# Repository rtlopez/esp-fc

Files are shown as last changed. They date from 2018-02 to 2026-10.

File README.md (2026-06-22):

# ESP-FC Flight Controller

The mini, DIY, Low cost, ESP32 based, high performance flight controller for hobbyists.

# Features

* Espressif targets (ESP32, ESP32-S3)
* ESC protocols (PWM, Oneshot125/42, Multishot, Brushed, Dshot150/300/600 bidirectional)
* PPM, SBUS, IBUS and CRSF Receivers
* Builtin ESP-NOW receiver and WiFi configuration [read more...](/docs/wireless.md)
* SPI and I2C gyro modules support (MPU6050, MPU9250, ICM20602, ICM42688, BMI160)
* Flight modes (ACRO, ANGLE, AIRMODE)
* Frames (Quad X)
* Betaflight configuration tool compatible (v10.10)
* Configurable Gyro Filters (LPF, Dynamic Notches, dTerm, RPM)
* Blackbox recording (OpenLog/OpenLager/Flash)
* Up to 4kHz gyro/loop on ESP32 with SPI gyro
* MSP and CLI protocol interface
* Resorce/Pin mapping
* In flight PID Tuning
* Buzzer, Led and voltage monitor
* Failsafe mode

# Documentation

In this repository you can find firmware code that allows you to build your own flight controller. For convenience it mimics Betaflight 4.2 compability, so that it can be configured using [betaflight-configurator](https://github.com/betaflight/betaflight-configurator). Also [online blackbox-log-viewer](https://blackbox.betaflight.com/) can be used to analyze blackbox logs. In most aspects it is similar to Betaflight, so that many configuration and tuning advices are helpfull here too. But you must be aware, that this software is not the same as Betaflight, there are some limitations and differences in functionality and performance.

> [!IMPORTANT]
> Before you begin, **read the following documentation carefully first!**.

 * [Setup Guide](/docs/setup.md)
 * [Wiring](/docs/wiring.md)
 * [CLI Commands](/docs/cli.md)
 * [WIFI and ESP-NOW Receiver](/docs/wireless.md)

Join our **[Discord Channel](https://discord.gg/jhyPPM5UEH)** to get help

# Quick Start

## Requirements

Hardware:
* ESP32 or ESP32-S3 board
* MPU9250 SPI or MPU6050 I2C gyro (GY-88, GY-91, GY-521 or similar)
* PDB with 5V BEC
* Buzzer and some electronic components (optional).

Software:
* [Betaflight Configurator](https://github.com/betaflight/betaflight-configurator/releases) (v10.10)
* [CH340 usb-serial converter driver](https://sparks.gogo.co.nz/ch340.html)

## Flashing

1. Download and unpack selected firmware from [Releases Page](https://github.com/rtlopez/esp-fc/releases)
2. Visit [ESP Tool Website](https://espressif.github.io/esptool-js/)
3. Click "Connect" and choose device port in dialog
4. Add firmware file and set Flash Address to `0x00`
5. Click "Program"
6. After success power cycle board

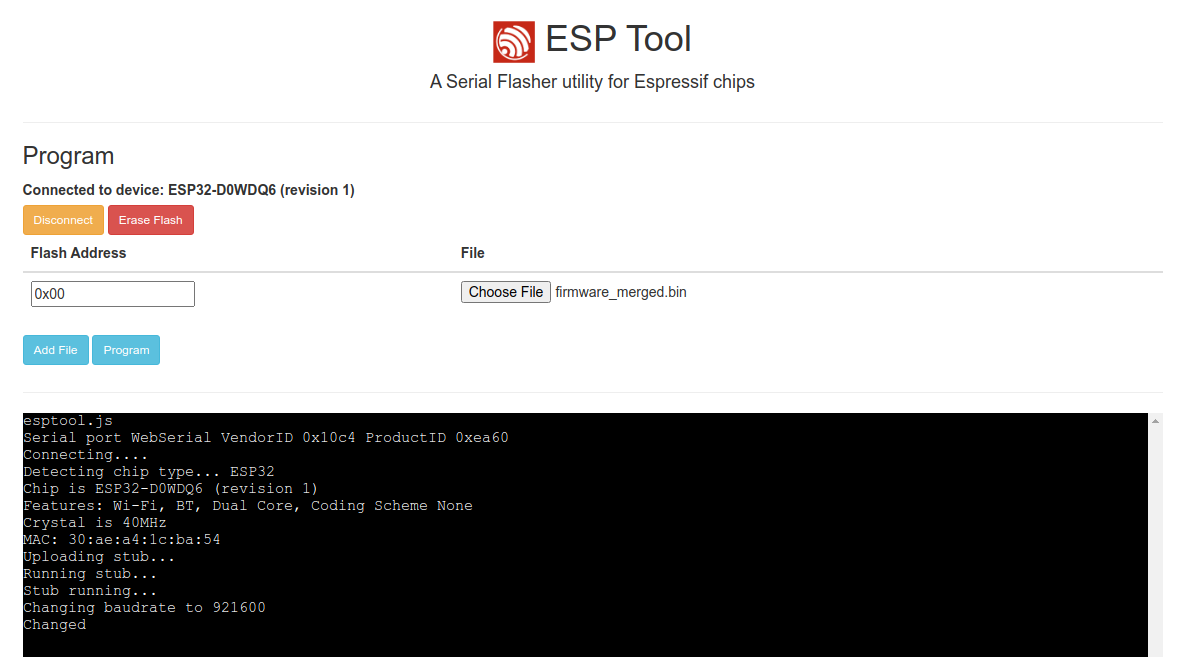
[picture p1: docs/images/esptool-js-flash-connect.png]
ESP-FC Flashing


## Setup

After flashing you need to configure few things first:

 1. Configure pinout according to your wiring, especially pin functions, you can find more information in [CLI Reference](/docs/cli.md)
 2. Connect to [Betaflight Configurator](https://github.com/betaflight/betaflight-configurator/releases) and setup to your preferences,
 3. Test motors without propellers
 4. Have fun ;)

> [!NOTE]
> Not all functions displayed in configurator are avalable in firmware. The rule of thumb is if you cannot change specific option in Betaflight Configurator, that means it is not supported. It usually rolls back to previous value after save. It is strongly recommended to follow [setup guide](/docs/setup.md).

## Wiring diagrams

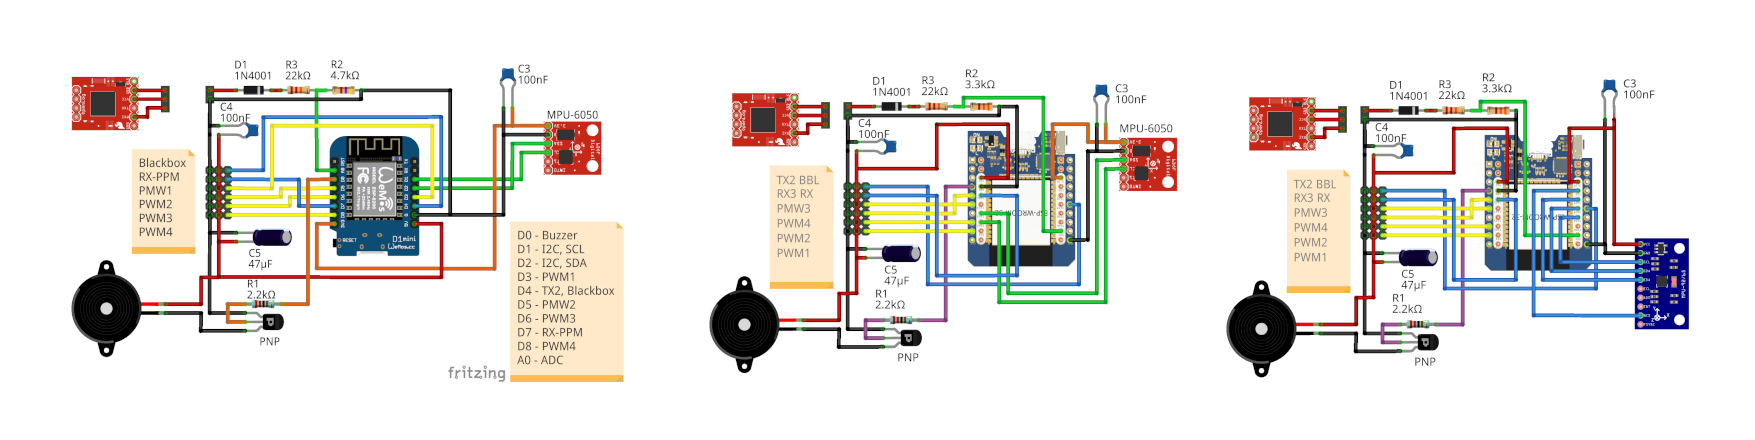
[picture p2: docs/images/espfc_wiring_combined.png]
ESP-FC example wiring diagrams


## Supported Modules

 * **ESP32** - recommended
 * **ESP32-S3** - recommended
 * **ESP32-S2** - experimantal
 * **ESP32-C3** - experimantal, lack of performance, no FPU
 * **RP2350** - experimantal, partially works
 * **RP2040** - experimantal, lack of performance, no FPU
 * **ESP8266** - obsolete, no longer developed

## Supported Sensors and Protocols

 * Gyro: MPU6050, MPU6000, MPU6500, MPU9250, ICM20602, ICM42688, BMI160
 * Barometers: BMP180, BMP280, SPL06
 * Magnetometers: HMC5883, QMC5883, AK8963, QMC5883P
 * Receivers: PPM, SBUS, IBUS, CRSF/ELRS
 * Esc Protocols: PWM, BRUSHED, ONESHOT125, ONESHOT42, MULTISHOT, DSHOT150, DSHOT300, DSHOT600
 * GPS: M8, M9, F9 & M10(dual band, all constellations configurable by cli)
 * Other protocols: MSP, CLI, BLACKBOX, ESPNOW

## Issues

You can report issues using Github [tracker](https://github.com/rtlopez/esp-fc/issues). 
You can also join our [Discord Channel](https://discord.gg/jhyPPM5UEH)

## Development

* Visual Studio Code
* [PlatformIO](https://platformio.org/install/ide?install=vscode) extension
* Git

## Todo

* Altitude Hold
* GPS Navigation
* MS5611 barometer
* Balancing robot controller

## Licence

This project is distributed under MIT Licence. Bear in mind that:

THE SOFTWARE IS PROVIDED "AS IS", WITHOUT WARRANTY OF ANY KIND, EXPRESS OR
IMPLIED, INCLUDING BUT NOT LIMITED TO THE WARRANTIES OF MERCHANTABILITY,
FITNESS FOR A PARTICULAR PURPOSE AND NONINFRINGEMENT. IN NO EVENT SHALL THE
AUTHORS OR COPYRIGHT HOLDERS BE LIABLE FOR ANY CLAIM, DAMAGES OR OTHER
LIABILITY, WHETHER IN AN ACTION OF CONTRACT, TORT OR OTHERWISE, ARISING FROM,
OUT OF OR IN CONNECTION WITH THE SOFTWARE OR THE USE OR OTHER DEALINGS IN THE
SOFTWARE.

## Donations
If you like this project and you want it to be still developed, you can support me a little.

* BTC: 1Lopez7yPtbyjfLGe892JfheDFJMMt43tW
* LTC: LV3G3sJxz9AYpDMYUp8e1LCmerFYxVY3ak

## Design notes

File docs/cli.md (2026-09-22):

# ESP-FC CLI Reference

## Help
```
help
available commands:
 help
 dump
 get param
 set param value ...
 cal [gyro]
 defaults
 save
 reboot
 scaler
 mixer
 stats
 status
 version
```

## Informational

### Version

```
version
ESPF ESP32S3 v0.0.0 0000000 Mar 13 2025 23:16:36 api=1.43 gcc=8.4.0 std=201703
```

### Status
```
status
ESPF ESP32S3 v0.0.0 0000000 Mar 13 2025 23:16:36 api=1.43 gcc=8.4.0 std=201703
STATUS:
    cpu freq: 240 MHz
  gyro clock: 3200 Hz
   gyro rate: 1600 Hz
   loop rate: 1600 Hz
  mixer rate: 1600 Hz
  accel rate: 400 Hz
   baro rate: 0 Hz
    mag rate: 0 Hz

     devices: BMI160/I2C
       input: 43 Hz, 0.00 Hz, 0.14
   arm flags: FAILSAFE RX_FAILSAFE CLI MSP
 rescue mode: 0
      uptime: 6.4
```

### Statisticss

Ensure that total CPU usage doesn't exceed 60-70%
```
stats
ESPF ESP32S3 v0.0.0 0000000 Mar 13 2025 23:16:36 api=1.43 gcc=8.4.0 std=201703
    cpu freq: 240 MHz
  gyro clock: 3200 Hz
   gyro rate: 1600 Hz
   loop rate: 1600 Hz
  mixer rate: 1600 Hz
  accel rate: 400 Hz
   baro rate: 0 Hz
    mag rate: 0 Hz

gyro_r: 187us,  117us/i,  18.7%,  1600 Hz
gyro_f:  14us,    9us/i,   1.4%,  1600 Hz
 acc_r:  45us,  114us/i,   4.5%,   399 Hz
 acc_f:   2us,    5us/i,   0.2%,   399 Hz
 imu_p:   4us,   10us/i,   0.4%,   399 Hz
 pid_o:   2us,    1us/i,   0.2%,  1600 Hz
 pid_i:   2us,    1us/i,   0.2%,  1600 Hz
 mix_p:  11us,    7us/i,   1.1%,  1600 Hz
 mix_w:  39us,   24us/i,   3.9%,  1600 Hz
 mix_r:   3us,    2us/i,   0.3%,  1600 Hz
  rx_r:   7us,    9us/i,   0.7%,   800 Hz
  rx_s:   2us,    3us/i,   0.2%,   800 Hz
  rx_a:   0us,    1us/i,   0.0%,    51 Hz
serial:   6us,    6us/i,   0.6%,   962 Hz
  wifi:   1us,    2us/i,   0.1%,   318 Hz
   bat:   7us,   65us/i,   0.7%,   102 Hz
 cpu_0: 278us,  174us/i,  27.8%,  1600 Hz
 cpu_1: 108us,   54us/i,  10.8%,  1999 Hz
  TOTAL: 386us, 23.1%
```

## Configuration

 - **defaults** - restore defaults
 - **save** - persist configuration after changes
 - **reboot** - reboot board

> [!IMPORTANT]
> if you change any parameter, remember to apply `save` and `reboot`. Without that some changes might not take effect.

## Configuration parameters

 - **dump** - dump all parameters
 - **get parameter_name** - get paramter value, list matching patameters with current values
 - **set paramter value1 [value2] [value3]** - set parameter to new value (some parameters store multiple values, ex. input)

Many parameters have similar name and meaning like Betaflight.

### Configuration examples

Get single value
```
# get gyro_lpf_type
set gyro_lpf_type PT1
```

Get multiple values
```
# get output_
set mixer_output_limit 100
set output_motor_protocol DSHOT150
set output_motor_async 0
set output_motor_rate 480
set output_servo_rate 0
set output_min_command 1000
set output_min_throttle 1050
set output_max_throttle 2000
set output_dshot_idle 450
set output_0 M N 1000 1500 2000
set output_1 M N 1000 1500 2000
set output_2 M N 1000 1500 2000
set output_3 M N 1000 1500 2000
set pin_output_0 0
set pin_output_1 14
set pin_output_2 12
set pin_output_3 15
```

Setting single value
```
set pin_output_0 0
```
> [!NOTE]
> You don't need to use `=` character for assignment

Setting milti-argument values
```
set output_0 S R
```
Note that you don't have to enter all values, you can ommit last values if they are not changed.

## Specific parameters reference

### Pin functions

Default pin assignments for ESP32-S3 is listed below
```
set pin_input_rx 6
set pin_output_0 39
set pin_output_1 40
set pin_output_2 41
set pin_output_3 42
set pin_button -1
set pin_buzzer 5
set pin_led -1
set pin_serial_0_tx 43
set pin_serial_0_rx 44
set pin_serial_1_tx 16
set pin_serial_1_rx 15
set pin_serial_2_tx 18
set pin_serial_2_rx 17
set pin_i2c_scl 10
set pin_i2c_sda 9
set pin_input_adc_vbat 1
set pin_input_adc_ibat 4
set pin_spi_0_sck 12
set pin_spi_0_mosi 11
set pin_spi_0_miso 13
set pin_spi_cs_0 8
set pin_spi_cs_1 7
set pin_spi_cs_2 -1
set pin_buzzer_invert 1
set pin_led_invert 0
```

You can swap two motor outputs (example 0 and 3) by running commands

```
set pin_output_0 42
set pin_output_3 39
save
reboot
```

### Input channel config
```
set input_0 0 1000 1500 2000 A 1500
set input_{channel} {map} {min} {neutral} {max} {fs_mode} {fs_value}
```
 - `{channel}`: raw rc channel (0-index)
 - `{map}`: map raw channel to input channel (0-index)
 - `{min/neutral/max}`: same as `rxrange` to adjust radio endpoints, scale rx input range to 1000/1500/2000, enter your min/mid/max values transmitted by radio.
 - `{fs_mode}`: fail safe mode, can be A: auto, H: hold, S: set
 - `{fs_value}`: value to use when fsMode is S(set)

### Output channel config
```
set output_0 M N 1000 1500 2000
set output_{channel} {type} {inverse} {min} {neutral} {max}
```
 - `{channel}`: output channel (0-index)
 - `{type}`: output type, can be M: motor, S: servo
 - `{inverse}`: inverse output, can be set to N: normal, R: reversed
 - `{min/neutral/max}`: limit/adjust output

### Mode conditions
```
set mode_{index} {id} {channel} {min} {max} {logic_mode} {link_id}
set mode_0 0 4 1300 2100 0 0
```
 - `{index}`: mode activator index
 - `{id}`: mode Id
 - `{channel}`: observed input channel (0-index, must be greather than 3)
 - `{min/max}`: activation range, if both are set to 900, it means inactive
 - `{logic_mode}`: NOT IMPLEMENTED, used by configurator but ignored by firmare
 - `{link_id}` - NOT IMPLEMENTED, used by configurator but ignored by firmare

Mode IDs:
 - 0: arming
 - 1: angle
 - 2: air mode
 - 3: buzzer
 - 4: failsafe

### Serial port configuration
```
set serial_0 1 115200 0
set serial_{index} {function} {msp_baud} {blackbox_baud}
```
 - `{index}`: port number (0-index)
 - `{function}`: function id
 - `{msp_baud}`: msp baud rate
 - `{blackbox_baud}`: blackbox baud rate (unused)

Serial Functions:
 - 0: none
 - 1: msp
 - 128: blackbox

### Scaler configuration

It's diferrent version of inflight adjustments, allow to control few parameters with rc channel, ex. by potentiomenters.

```
set scaler_0 769 5 20 400
set scaler_{index} {dimensions} {channel} {min_scale} {max_scale}
```

 - `{index}`: scaler instance (0-3)
 - `{dimensions}`: combination of dimentions
 - `{channel}`: observed iput channel (0-index, must be greather than 3)
 - `{min_scale/max_scale}`: min and max scale in percent

Scaler Dimensions:
 - 1: PID P component of inner loop
 - 2: PID I component of inner loop
 - 4: PID D component of inner loop
 - 8: PID F component of inner loop
 - 16: PID P component of outer loop
 - 32: PID I component of outer loop
 - 64: PID D component of outer loop
 - 128: PID F component of outer loop
 - 256: Roll Axis
 - 512: Pitch Axis
 - 1024: Yaw Axis

**Note 1**: To apply scaling you need to combine at least one PID component and Axis. You can also control multiple parameters by single channels. For example to control inner P and D on Pitch and Roll axes you need to use value 771 as dimentions (1 + 2 + 256 + 521),

**Note 2**: the scale is not uniform, in neutral position it is always 100 percent to represent original config value, if minimum is negative, then neutral position represents 0.

**Note 3**: inner loop is main loop for acro mode, outer loop refers to level mode.

### Mixer

There are few predefined mixers that can be used out-of-the box. You can choose it by setting paramter `mixer_type`

```
set mixer_type QUADX
```

Currently allowed are only:
 - QUADX (default)
 - QUAD1234 (untested)
 - TRI (untested)

You can debug mixer configuration with `mixer` command

```
# mixer
set mix_outputs 4
set mix_0 1 0 -100
set mix_1 1 1 -100
set mix_2 1 2 100
set mix_3 1 3 100
set mix_4 2 0 100
set mix_5 2 1 -100
set mix_6 2 2 100
set mix_7 2 3 -100
set mix_8 3 0 -100
set mix_9 3 1 100
set mix_10 3 2 100
set mix_11 3 3 -100
set mix_12 4 0 100
set mix_13 4 1 100
set mix_14 4 2 100
set mix_15 4 3 100
set mix_16 0 0 0
```

### Custom Mixer

To activate custom mixer you need to set mixer type to custom and declare number of outputs.

```
set mixer_type CUSTOM
set mix_outputs 4
```

Then apply your custom rules
```
set mix_0 0 0 0
set mix_{index} {src} {dst} {rate}
```
 - `{index}`: rule index
 - `{src}`: mixer source channel
 - `{dst}`: output channel (0-index)
 - `{rate}`: mix rate in percent

> [!IMPORTANT]
> You need to add a termination rule at the end, to inform mixer to stop processing. In this case set `src` argument to 0. When mixer encounters such a rule, it stops processing and ignore next rules. You can add maximum 64 rules.

Mixer Sources:
 - 0: null for termination rule
 - 1: stabilized roll
 - 2: stabilized pitch
 - 3: stabilized yaw
 - 4: thrust
 - 5: rc roll
 - 6: rc pitch
 - 7: rc yaw
 - 8: rc thrust
 - 9: rc aux 1
 - 10: rc aux 2
 - 11: rc aux 3

## All supported parameters

Use `dump` command to backup all your settings. You can then load you configuration in CLI tab. Below you can find full list of parameters.

```
set feature_gps 0
set feature_dyn_notch 0
set feature_motor_stop 0
set feature_rx_ppm 0
set feature_rx_serial 1
set feature_rx_spi 0
set feature_soft_serial 0
set feature_telemetry 0
set debug_mode NONE
set debug_axis 1
set gyro_bus AUTO
set gyro_dev AUTO
set gyro_dlpf 256Hz
set gyro_align DEFAULT
set gyro_lpf_type PT1
set gyro_lpf_freq 100
set gyro_lpf2_type PT1
set gyro_lpf2_freq 213
set gyro_lpf3_type FO
set gyro_lpf3_freq 150
set gyro_notch1_freq 0
set gyro_notch1_cutoff 0
set gyro_notch2_freq 0
set gyro_notch2_cutoff 0
set gyro_dyn_lpf_min 170
set gyro_dyn_lpf_max 425
set gyro_dyn_notch_q 300
set gyro_dyn_notch_count 4
set gyro_dyn_notch_min 80
set gyro_dyn_notch_max 400
set gyro_rpm_harmonics 3
set gyro_rpm_q 500
set gyro_rpm_min_freq 100
set gyro_rpm_fade 30
set gyro_rpm_weight_1 100
set gyro_rpm_weight_2 100
set gyro_rpm_weight_3 100
set gyro_rpm_tlm_lpf_freq 150
set gyro_offset_x -6
set gyro_offset_y -1
set gyro_offset_z 8
set accel_bus AUTO
set accel_dev AUTO
set accel_lpf_type BIQUAD
set accel_lpf_freq 15
set accel_offset_x 0
set accel_offset_y 0
set accel_offset_z 0
set mag_bus AUTO
set mag_dev NONE
set mag_align DEFAULT
set mag_filter_type BIQUAD
set mag_filter_lpf 10
set mag_offset_x 0
set mag_offset_y 0
set mag_offset_z 0
set mag_scale_x 1000
set mag_scale_y 1000
set mag_scale_z 1000
set baro_bus AUTO
set baro_dev NONE
set baro_lpf_type BIQUAD
set baro_lpf_freq 3
set gps_min_sats 8
set gps_set_home_once 1
set board_align_roll 0
set board_align_pitch 0
set board_align_yaw 0
set vbat_source NONE
set vbat_scale 100
set vbat_mul 1
set vbat_div 10
set vbat_cell_warn 350
set ibat_source NONE
set ibat_scale 100
set ibat_offset 0
set fusion_mode MAHONY
set fusion_gain_p 50
set fusion_gain_i 5
set input_rate_type ACTUAL
set input_roll_rate 20
set input_roll_srate 40
set input_roll_expo 0
set input_roll_limit 1998
set input_pitch_rate 20
set input_pitch_srate 40
set input_pitch_expo 0
set input_pitch_limit 1998
set input_yaw_rate 30
set input_yaw_srate 36
set input_yaw_expo 0
set input_yaw_limit 1998
set input_deadband 3
set input_min 885
set input_mid 1500
set input_max 2115
set input_filter_type FILTER
set input_lpf_type PT3
set input_lpf_freq 0
set input_lpf_factor 50
set input_ff_lpf_type PT3
set input_ff_lpf_freq 0
set input_rssi_channel 0
set input_0 0 1000 1500 2000 A 1500
set input_1 1 1000 1500 2000 A 1500
set input_2 3 1000 1500 2000 A 1500
set input_3 2 1000 1500 2000 A 1000
set input_4 4 1000 1500 2000 H 1500
set input_5 5 1000 1500 2000 H 1500
set input_6 6 1000 1500 2000 H 1500
set input_7 7 1000 1500 2000 H 1500
set input_8 8 1000 1500 2000 H 1500
set input_9 9 1000 1500 2000 H 1500
set input_10 10 1000 1500 2000 H 1500
set input_11 11 1000 1500 2000 H 1500
set input_12 12 1000 1500 2000 H 1500
set input_13 13 1000 1500 2000 H 1500
set input_14 14 1000 1500 2000 H 1500
set input_15 15 1000 1500 2000 H 1500
set failsafe_delay 4
set failsafe_kill_switch 0
set vtx_power 0
set vtx_channel 8
set vtx_band 1
set vtx_low_power_disarm 0
set serial_0 1 115200 0
set serial_1 1 115200 0
set serial_2 64 115200 0
set serial_soft_0 1 115200 0
set serial_usb 1 115200 0
set scaler_0 0 0 20 400
set scaler_1 0 0 20 400
set scaler_2 0 0 20 400
set mode_0 0 4 900 900 0 0
set mode_1 0 4 900 900 0 0
set mode_2 0 4 900 900 0 0
set mode_3 0 4 900 900 0 0
set mode_4 0 4 900 900 0 0
set mode_5 0 4 900 900 0 0
set mode_6 0 4 900 900 0 0
set mode_7 0 4 900 900 0 0
set pid_sync 1
set pid_roll_p 42
set pid_roll_i 85
set pid_roll_d 24
set pid_roll_f 72
set pid_pitch_p 46
set pid_pitch_i 90
set pid_pitch_d 26
set pid_pitch_f 76
set pid_yaw_p 45
set pid_yaw_i 90
set pid_yaw_d 0
set pid_yaw_f 72
set pid_level_p 45
set pid_level_i 0
set pid_level_d 0
set pid_level_angle_limit 55
set pid_level_rate_limit 300
set pid_level_lpf_type PT1
set pid_level_lpf_freq 90
set pid_yaw_lpf_type PT1
set pid_yaw_lpf_freq 90
set pid_dterm_lpf_type PT1
set pid_dterm_lpf_freq 128
set pid_dterm_lpf2_type PT1
set pid_dterm_lpf2_freq 128
set pid_dterm_notch_freq 0
set pid_dterm_notch_cutoff 0
set pid_dterm_dyn_lpf_min 60
set pid_dterm_dyn_lpf_max 145
set pid_dterm_weight 30
set pid_iterm_limit 30
set pid_iterm_zero 1
set pid_iterm_relax RP
set pid_iterm_relax_cutoff 15
set pid_tpa_scale 10
set pid_tpa_breakpoint 1650
set mixer_sync 1
set mixer_type QUADX
set mixer_yaw_reverse 0
set mixer_throttle_limit_type NONE
set mixer_throttle_limit_percent 100
set mixer_output_limit 100
set output_motor_protocol DSHOT300
set output_motor_async 0
set output_motor_rate 480
set output_motor_poles 14
set output_servo_rate 0
set output_min_command 1000
set output_min_throttle 1070
set output_max_throttle 2000
set output_dshot_idle 550
set output_dshot_telemetry 0
set output_0 M N 1000 1500 2000
set output_1 M N 1000 1500 2000
set output_2 M N 1000 1500 2000
set output_3 M N 1000 1500 2000
set pin_input_rx 6
set pin_output_0 39
set pin_output_1 40
set pin_output_2 41
set pin_output_3 42
set pin_button -1
set pin_buzzer 5
set pin_led -1
set pin_serial_0_tx 43
set pin_serial_0_rx 44
set pin_serial_1_tx 16
set pin_serial_1_rx 15
set pin_serial_2_tx 18
set pin_serial_2_rx 17
set pin_i2c_scl 13
set pin_i2c_sda 12
set pin_input_adc_vbat 1
set pin_input_adc_ibat 4
set pin_spi_0_sck -1
set pin_spi_0_mosi -1
set pin_spi_0_miso -1
set pin_spi_cs_0 8
set pin_spi_cs_1 7
set pin_spi_cs_2 -1
set pin_buzzer_invert 1
set pin_led_invert 0
set i2c_speed 800
set rescue_config_delay 30
set telemetry_interval 1000
set blackbox_dev NONE
set blackbox_mode NORMAL
set blackbox_rate 32
set blackbox_log_acc 1
set blackbox_log_alt 1
set blackbox_log_bat 1
set blackbox_log_debug 1
set blackbox_log_gps 1
set blackbox_log_gyro 1
set blackbox_log_gyro_raw 1
set blackbox_log_mag 1
set blackbox_log_motor 1
set blackbox_log_pid 1
set blackbox_log_rc 1
set blackbox_log_rpm 1
set blackbox_log_rssi 1
set blackbox_log_sp 1
set model_name
set wifi_ssid
set wifi_pass
set wifi_tcp_port 1111
set mix_outputs 0
set mix_0 0 0 0
set mix_1 0 0 0
set mix_2 0 0 0
set mix_3 0 0 0
set mix_4 0 0 0
set mix_5 0 0 0
set mix_6 0 0 0
set mix_7 0 0 0
set mix_8 0 0 0
set mix_9 0 0 0
set mix_10 0 0 0
set mix_11 0 0 0
set mix_12 0 0 0
set mix_13 0 0 0
set mix_14 0 0 0
set mix_15 0 0 0
set mix_16 0 0 0
set mix_17 0 0 0
set mix_18 0 0 0
set mix_19 0 0 0
set mix_20 0 0 0
set mix_21 0 0 0
set mix_22 0 0 0
set mix_23 0 0 0
set mix_24 0 0 0
set mix_25 0 0 0
set mix_26 0 0 0
set mix_27 0 0 0
set mix_28 0 0 0
set mix_29 0 0 0
set mix_30 0 0 0
set mix_31 0 0 0
set mix_32 0 0 0
set mix_33 0 0 0
set mix_34 0 0 0
set mix_35 0 0 0
set mix_36 0 0 0
set mix_37 0 0 0
set mix_38 0 0 0
set mix_39 0 0 0
set mix_40 0 0 0
set mix_41 0 0 0
set mix_42 0 0 0
set mix_43 0 0 0
set mix_44 0 0 0
set mix_45 0 0 0
set mix_46 0 0 0
set mix_47 0 0 0
set mix_48 0 0 0
set mix_49 0 0 0
set mix_50 0 0 0
set mix_51 0 0 0
set mix_52 0 0 0
set mix_53 0 0 0
set mix_54 0 0 0
set mix_55 0 0 0
set mix_56 0 0 0
set mix_57 0 0 0
set mix_58 0 0 0
set mix_59 0 0 0
set mix_60 0 0 0
set mix_61 0 0 0
set mix_62 0 0 0
set mix_63 0 0 0
```

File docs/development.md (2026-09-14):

# Development

## Building and flashing

```
pio run                      # build all targets
pio run -e <target>          # build specific target like: esp32,esp32s3,...
pio run -e esp32 -t upload   # build and flash device
pio test -e native           # run unit tests
pio check                    # run static anlysis
pio run -t check_format      # check code style
pio run -e native -t format  # format code
```

## Docker

If you don't want to install PlatformIO, you can use Docker Environment

general usage
```
docker compose run --rm espfc <pio command>
```

examples

```
docker compose run --rm espfc pio run -e esp32
docker compose run --rm espfc pio test -e native
```

> [!NOTE]
> Keep in mind, that to be able to flash device, additional effort is required as by default docker is isolated enviroment devices are't accessible.

## VSCode

This project is based on [platformio](https://platformio.org/), it is recommended to install it as VSCode IDE extension.

1. if you don't have VSCode yet? visit https://code.visualstudio.com/download
2. then install https://platformio.org/install/ide?install=vscode

## Contribution

If you want to include your changes in this project, you need to make PR (Pull Request) on github.

### How to contribute to Esp-fc project

1. Fork the repository

Click the Fork button on the project’s GitHub page to create your own copy.

2. Clone your fork

```
git clone https://github.com/your-username/project-name.git
```

3. Create a new branch

```
git checkout -b feature/my-change
```

4. Make your changes

- Edit files, add features, or fix bugs.
- Run tests and static anlysis tools.
- Collect eveidence that proves your changes do the job

5. Commit your changes

```
git add .
git commit -m "Add short description of changes"
```

6. Push the branch to your fork

```
git push origin feature/my-change
```

7. Open a Pull Request (PR)

Go to your fork on GitHub and click Compare & pull request. Add a clear title and description, then submit the PR. Wait for review. Project maintainers may request changes before merging your contribution.

### What requirements must be met for a PR to be accepted?

1. Provide clear change description with reasoning what type of problem you are trying to resolve
2. Provide evidence that feature you deliver works as expected and do not breaks any existing functionality
3. In PR address only one problem or feature
4. Ensure that unittests are passing and static alanysis tools do not report any errors
5. Avoid commiting unnecesary changes
6. Untested changes will not be accepted

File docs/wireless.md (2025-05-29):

# ESP-FC Wireless functions

Espressif modules have a built-in WiFi module that can be used for configuration and control.

## WiFi configuration

> [!NOTE]
> To be able to configure device using WiFi connection, you need to enable `SOFTSERIAL` function. WiFi function can only be used to configure device. Whilst WiFi is active, it is not possible to ARM controller and reboot is required.

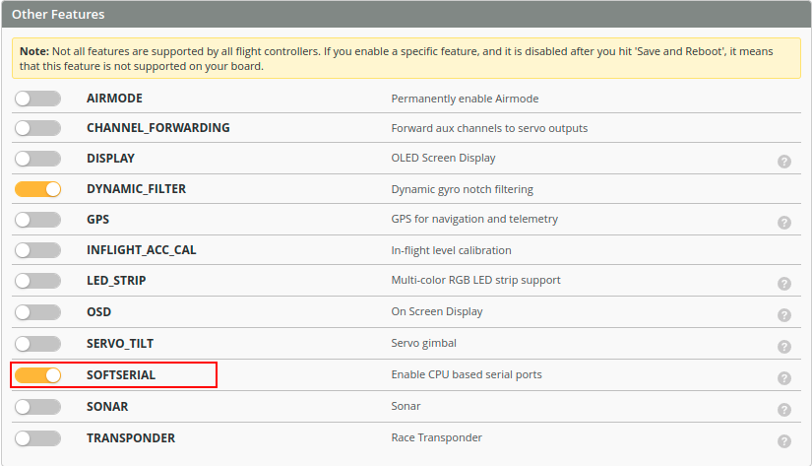
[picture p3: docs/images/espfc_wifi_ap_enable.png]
Enable WiFi


WiFi will start its own Access-Point if board will not detect receiver signal for at least 30 seconds (stay in failsafe mode since boot). Name of this AP is `ESP-FC` and it is open network. If you connect to this AP, then choose `Manual Selection` and type `tcp://192.168.4.1:1111` 

Connect to ESP-FC AP

You can also automatically connect ESP-FC to your home network. To achive that, go to the CLI tab, and enter your network name and secret.
```
set wifi_ssid MY-HOME-NET
set wifi_pass MY-HOME-PASS
```
> [!NOTE]
> Network name and pass must not contains spaces.

then you can check status of connection by typing `wifi` in CLI tab.
```
wifi 
ST IP4: tcp://0.0.0.0:1111
ST MAC: 30:30:F9:6E:10:74
AP IP4: tcp://192.168.4.1:1111
AP MAC: 32:30:F9:6E:10:74
```
In this mode you need to discover IP address granted by DHCP. In line `ST IP4` is the address that you need to use in configurator. If there is `0.0.0.0`, that means that FC was not able to connect to home network.

## ESP-NOW control

ESP-NOW is a proprietary wireless communication protocol defined by Espressif, which enables the direct, quick and low-power control of smart devices, without the need of a router. 

As there are no real transmitters usng this protocol on the market, you have to build your own transmitting module first. If you alredy own RC transmitter with JR bay, you can use another ESP32 module. In this case follow [espnow-rclink-tx](https://github.com/rtlopez/espnow-rclink-tx) instructions.

In ESP-FC you have to choose `SPI Rx (e.g. built-in Rx)` as Receiver mode in Receiver tab.

ESP-FC ESP-NOW Reciever

Transmitter and receiver binds automatically after power up, you don't need to do anything. Recomended startup procedure is:
1. turn on transmitter first
2. next power up receiver/flight controller

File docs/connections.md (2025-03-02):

# WEMOS D1 MINI pinout
```
Pin | Function         | ESP-8266 Pin | ESPFC external device
----+------------------+--------------+----------------------------------------------
TX  | TXD0             | TXD, GPIO1   | (UART0 TX) | CLI | MSP | OSD
RX  | RXD0             | RXD, GPIO3   | (UART0 RX) | CLI | MSP | OSD
A0  | Analog In,  3.3V | A0           | Batery voltage or current sensor, analog only
D0  | IO               | GPIO16       | LED | BUZZER (output recommended, no interrupts)
D1  | IO, SCL          | GPIO5        | I2C Gyro, Compas, Pressure and other sensors
D2  | IO, SDA          | GPIO4        | I2C Gyro, Compas, Pressure and other sensors
D3  | IO, PU           | GPIO0        | PWM 1 (servo/motor)
D4  | IO, PU, LD, TXD1 | GPIO2        | Blackbox (UART1 TX)
D5  | IO, SCK          | GPIO14       | PWM 2 (servo/motor)
D6  | IO, MISO         | GPIO12       | PWM 3 (servo/motor)
D7  | IO, MOSI         | GPIO13       | PPM RX | PWM
D8  | IO, SS, PD       | GPIO15       | PWM 4 (servo/motor)
G   | Ground           | GND          | Ground
5V  | 5V               | N/A          | 5V power
3V3 | 3.3V             | 3.3V         | 3.3V power - to I2C devices
RST | Reset            | RST          | Reset switch (optional)
```

## Legend:
```
   PU - 10k pull up
   PD - 10k pull down
 RXD0 - UART0 hardware RX
 TXD0 - UART0 hardware TX
 TXD1 - UART1 hardware TX
   LD - builtin LED
```

## Notice:
```
 A0 - In ESP-8266 is 1.0V range, Wemos has 220k:100k divider for 3.3V range, 22k:4k7 additional divider required for 4S Lipo
 D0 - No iterrupts (recommended output)
 D3, GPIO0 - if low at boot, then board enters to flashing mode (avoid using as input)
 D4, GPIO2 - must be high during flashing (avoid using as input)
 D8, GPIO15 - must be low during flashing or boot (avoid using as input)
```
https://github.com/esp8266/esp8266-wiki/wiki/Boot-Process#esp-boot-modes

## Wemos D1 mini board layout:
```
      /-----------\
   TX |           | RST
   RX |           | A0
   D1 |           | D0
   D2 |           | D5 ~>
<~ D3 |           | D6 ~>
<~ D4 |           | D7 ~<
  GND |           | D8 ~>
   5v |           | 3.3V
      +---|---|---+
           USB
```

# ESP32 pinout
```
Pin | Name | Function                                   | ESPFC external device
----+------+--------------------------------------------+----------------------------------------------
 0  |      | PU,ADC2_CH1,CLK_OUT1                       | >  BUTTON
 1  | TXD  | U0TXD,CLK_OUT3                             |    TX0, PROG, MSP
 2  |      | ADC2_CH2,HSPIWP,HS2_DATA0,SD_DATA0         | >  LED
 3  | RXD  | U0RXD,CLK_OUT2                             |    RX0, PROG, MSP
 4  |      | ADC2_CH0,HSPIHD,HS2_DATA1,SD_DATA1         |    M2
 5  |      | VSPICS0,HS1_DATA6                          | >  SPI_CS0_GYRO, SPI0_SS
12  | TD1  | PD,ADC2_CH5,MTDI,HSPIQ,HS2_DATA2,SD_DATA2  | >  M3, SPI1_MISO
13  | TCK  | ADC2_CH4,MTCK,HSPID,HS2_DATA3,SD_DATA3     |    SPI_CS1_BARO, SPI1_MOSI
14  | TMS  | ADC2_CH6,MTMS,HSPICLK,HS2_CLK,SD_CLK       | $  FREE, SPI1_SCK
15  | TD0  | PU,ADC2_CH3,MTDO,HSPICS0,HS2_CMD,SD_CMD    | >  FREE, SPI_CS2_SDCARD, SPI1_SS
16  |      | HS1_DATA4,U2RXD                            |    RX2
17  |      | HS1_DATA5,U2TXD                            |    TX2
18  |      | VSPICLK,HS1_DATA7                          |    SPI0_SCK
19  |      | VSPIQ,U0CTS                                |    SPI0_MISO
21  |      | VSPIHD                                     |    I2C0_SDA
22  |      | VSPIWP,U0RTS                               |    I2C0_SCL
23  |      | VSPID,HS1_STROBE                           |    SPI0_MOSI
25  |      | ADC2_CH8,DAC1                              |    M1
26  |      | ADC2_CH9,DAC2                              |    BUZZER
27  |      | ADC2_CH7                                   |    M0
32  |      | ADC1_CH4,XTAL                              |    RX1
33  |      | ADC1_CH5,XTAL                              |    TX1
34  |      | ADC1_CH6                                   | <$ ADC, INTR
35  |      | ADC1_CH7                                   | <  PPM, ADC, INTR
36  | SVP  | ADC1_CH0                                   | <  ADC_VOLTAGE
37  | -    | ADC1_CH1                                   | -  N/A
38  | -    | ADC1_CH2                                   | -  N/A
39  | SVN  | ADC1_CH3                                   | <  ADC_CURRENT
```

## Legend
```
 '>' recommended output only
 '<' input only
 '$' free
 '-' not available
```
GPIO `0, 2, 5, 12, 15` recommended as output because of boot process impact
GPIO `34-39` are input-only by chip
GPIO `6-11` are reserved for integrated flash
GPIO `20,24,28,29,30,31` does not exist

- GPIO0 - Low/GND	ROM serial bootloader for esptool.py, High/VCC	Normal execution mode
- GPIO2 - GPIO2 must also be either left unconnected/floating, or driven Low, in order to enter the serial bootloader. In normal boot mode (GPIO0 high), GPIO2 is ignored.
- GPIO12 - If driven High, flash voltage (VDD_SDIO) is 1.8V not default 3.3V. Has internal pull-down, so unconnected = Low = 3.3V. May prevent flashing and/or booting if 3.3V flash is used and this pin is pulled high, causing the flash to brownout. See the ESP32 datasheet for more details.
- GPIO15 - If driven Low, silences boot messages printed by the ROM bootloader. Has an internal pull-up, so unconnected = High = normal output.
- GPIO5 - configures SDIO Slave in "Download Boot"

https://github.com/espressif/esptool/wiki/ESP32-Boot-Mode-Selection

## ESP32 mini board layout
```
                  /-------------\
 GND      RST     |             |  TXD (1)    GND
  NC      SVP(36) |             |  RXD (3)    IO(27)
 SVN(39)   IO(26) |             |   IO(22)    IO(25)
  IO(35)   IO(18) |             |   IO(21)    IO(32)
  IO(33)   IO(19) |             |   IO(17)   TD1(12)
  IO(34)   IO(23) |             |   IO(16)    IO(04)
 TMS(14)   IO(05) |             |  GND        IO(00)
  NC      3V3     |             |  VCC(5v)    IO(02)
 SD2(09)  TCK(13) |             |  TD0(15)   SD1(08)
 CMD(11)  SD3(10) |             |  SD0(07)   CLK(06)
                  +----|---|----+
                        USB
```

# ESP32-S3

https://docs.espressif.com/projects/esp-idf/en/latest/esp32s3/api-reference/peripherals/gpio.html

```
Pin | Function             | ESPFC external device
----+------+---------------+----------------------------------------------
 0  | Strapping            |
 1  | ADC1_CH0             | ADC_VOLTAGE
 2  | ADC1_CH1             | DEBUG
 3  | ADC1_CH2, Strapping  |
 4  | ADC1_CH3             | ADC_CURRENT
 5  | ADC1_CH4             | BUZZER
 6  | ADC1_CH5             | PPM
 7  | ADC1_CH6             | SPI_CS_BARO
 8  | ADC1_CH7             | SPI_CS_GYRO
 9  | ADC1_CH8             | I2C_0_SDA
10  | ADC1_CH9             | I2C_0_SCK
11  | ADC2_CH0             | SPI_0_MOSI
12  | ADC2_CH1             | SPI_0_SCK
13  | ADC2_CH2             | SPI_0_MISO
14  | ADC2_CH3             | ?
15  | ADC2_CH4             | RX1
16  | ADC2_CH5             | TX1
17  | ADC2_CH6             | RX2
18  | ADC2_CH7             | TX2
19  | ADC2_CH8, USB        | USB
20  | ADC2_CH9, USB        | USB
21  | RTC_21               | ?
38  | RGB                  | LED_RGB
39  |                      | M0
40  |                      | M1
41  |                      | M2
42  |                      | M3
43  | U1TX                 | TX0
44  | U1RX                 | RX0
45  |                      | ?
46  | Strapping            | SPI_CS_SD
47  | Strapping            | ?
48  |                      | ?

RESERVED
26  | FLASH                |
27  | FLASH                |
28  | FLASH                |
29  | FLASH                |
30  | FLASH                |
31  | FLASH                |
32  | FLASH                |
33  | FLASH                |
34  | FLASH                |
35  | FLASH                |
36  | FLASH                |
37  | FLASH                |

UNAVAILABLE
22, 23, 24, 25
```

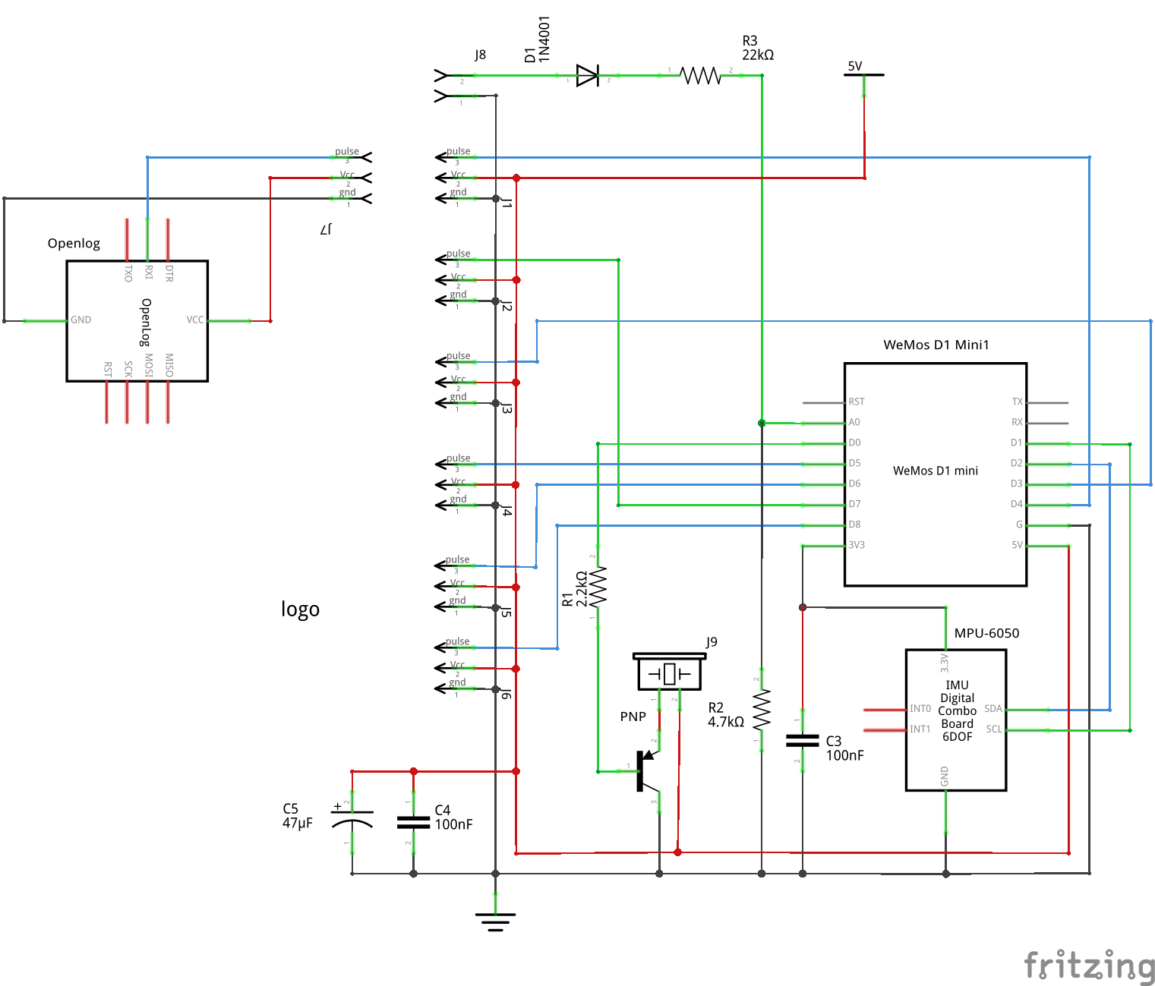
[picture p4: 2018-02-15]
docs/images/espfc_wemos_d1_mini_schematic.png

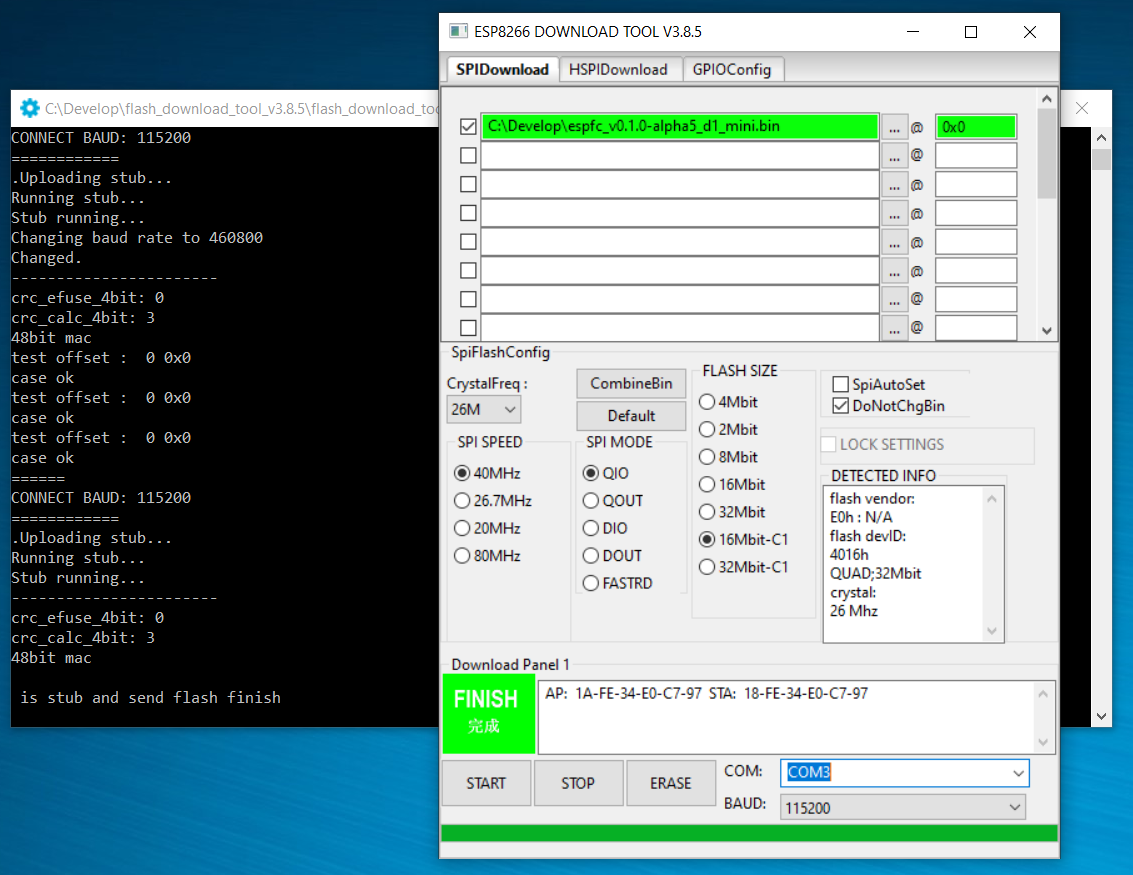
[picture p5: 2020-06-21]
docs/images/espfc_flashing.png

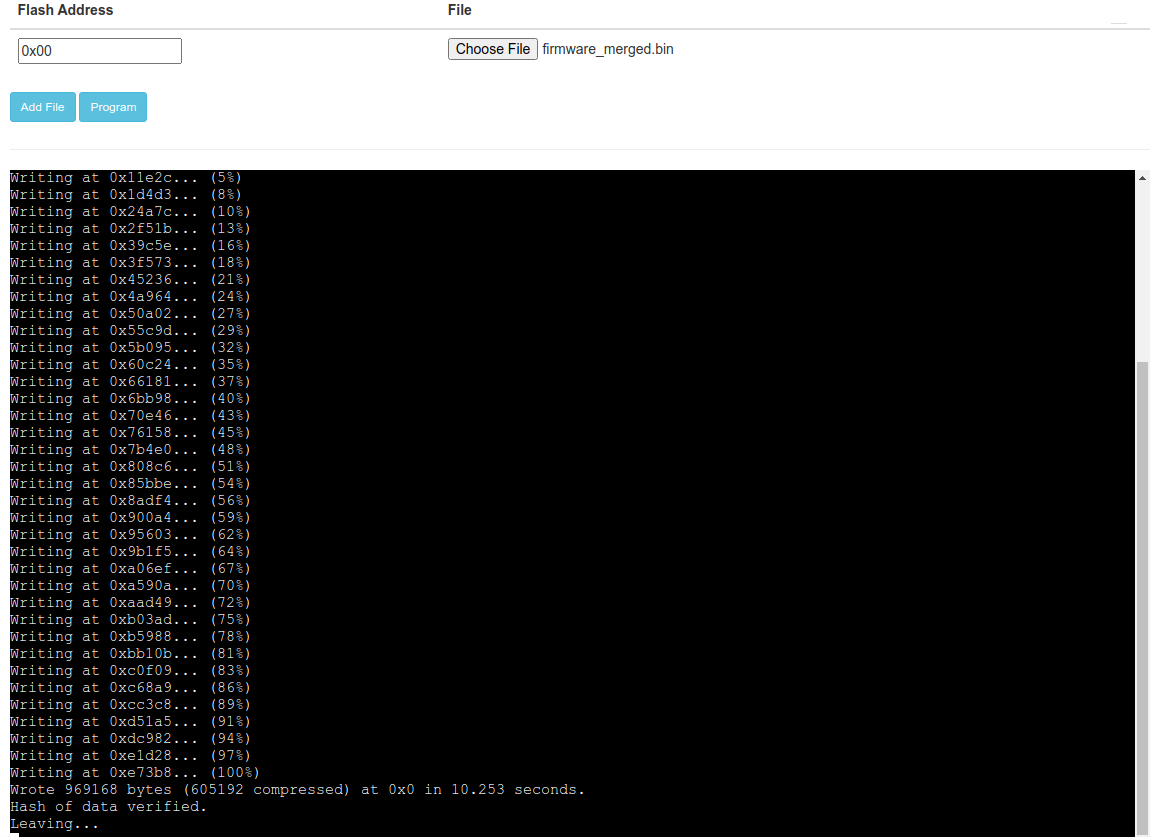
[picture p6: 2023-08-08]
docs/images/esptool-js-flash-flashed.png

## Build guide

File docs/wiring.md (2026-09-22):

# ESP-FC wiring examples and PIN mapping

ESP32 MCUs allows to remap pins, so the wiring is not final and you can remap intputs and outputs to your needs. To change pin function go to the CLI and use `get pin` command to check current assignment. For example, to set first output to pin 1 use command

`set pin_output_0 1`

Tu unmap pin function use -1 as pin number

`set pin_output_3 -1`

> [!NOTE]
> There are still some limitations in remapping. Not all pins can be used with all functions. Some pins are input only, others are strapping pins and may prevent from booting if used incorrectly. please consult MCU documentation for available options. Default layout is proven to work.

## Default I2C pin mapping for gyro modules

| Module Pin | CLI Name | ESP32 | ESP32-S3 |
|---|---|---:|---:|
| SCK/SCL | `pin_i2c_scl` | 22 | 10 |
| SDA/SDI | `pin_i2c_sda` | 21 | 9 |

> [!NOTE]
> I2C driver accepts only pins from 1 to 31

## Default SPI pin mapping gyro modules

| Module Pin  | CLI Name | ESP32 | ESP32-S3 |
|---|---|---:|---:|
| SCK/SCL | `pin_spi_0_sck`  | 18 | 12 |
| SDA/SDI | `pin_spi_0_mosi` | 23 | 11 |
| SAO/SDO/ADO | `pin_spi_0_miso` | 19 | 13 |
| NCS | `pin_spi_cs_0` |  5 |  8 |
| CSB* | `pin_spi_cs_1` | 13 |  7 |

**Note:** `CSB` is required for barometer on 10-DOF MPU-9250 modules

> [!TIP]
> For better performance preffer SPI

## Default Servo/Motor output mapping

| Motor  | CLI name | ESP32 | ESP32-S3 |
|---:|---|---:|---:|
| 1 | `pin_output_0` | 27 | 39 |
| 2 | `pin_output_1` | 25 | 40 |
| 3 | `pin_output_2` | 4 | 41 |
| 4 | `pin_output_3` | 12 | 42 |

## Default Uart/Serial pin mapping

| Uart | CLI name | ESP32 | ESP32-S3 |
|-----:|---|---:|---:|
| RX 1 | `pin_serial_0_rx` |  3 | 44 |
| TX 1 | `pin_serial_0_tx` |  1 | 43 |
| RX 2 | `pin_serial_1_rx` | 32 | 15 |
| TX 2 | `pin_serial_1_tx` | 33 | 16 |
| RX 3 | `pin_serial_2_rx` | 16 | 17 |
| TX 3 | `pin_serial_2_tx` | 17 | 18 |

## Default Analog pin mapping

| Uart | CLI name | ESP32 | ESP32-S3 |
|---:|---|---:|---:|
| Voltage | `pin_input_adc_vbat` |  36 | 1 |
| Current | `pin_input_adc_ibat` |  39 | 4 |

> [!NOTE]
> On ESP32 choose only pins assigned to ADC1 channels

## Default PPM receiver pin mapping

| Uart | CLI name | ESP32 | ESP32-S3 |
|---:|---|---:|---:|
| PPM | `pin_input_rx` |  35 | 6 |

## Other pin functions

| CLI name | ESP32 | ESP32-S3 | Comment |
|---|---:|---:|---|
| `pin_buzzer` |  0 | 5 | Status buzzer |
| `pin_led` |  26 | - | Status led |

## Example ESP32 SPI MPU-6500/MPU-9250 gyro

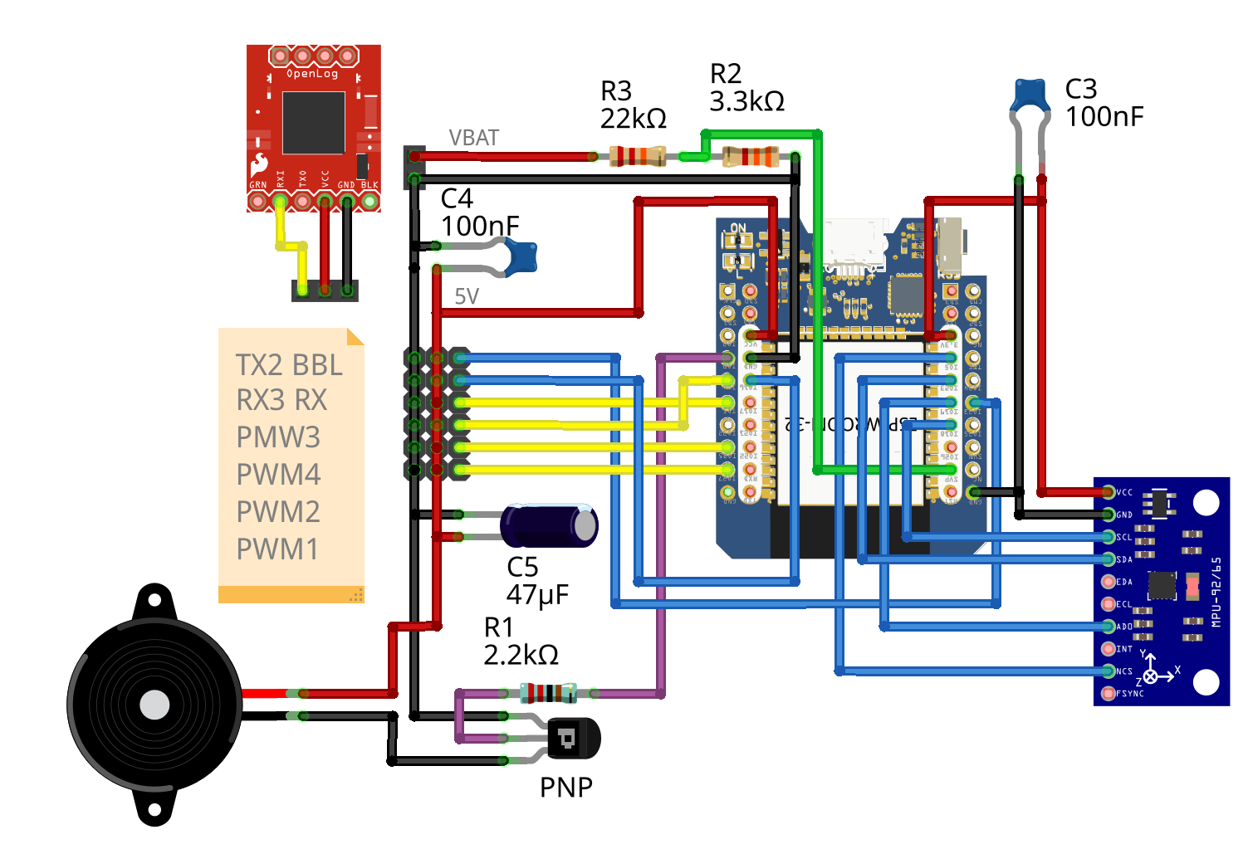
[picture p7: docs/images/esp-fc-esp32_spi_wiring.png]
ESP-FC ESP32 SPI Wiring


## Example ESP32 I2C MPU-6050 gyro

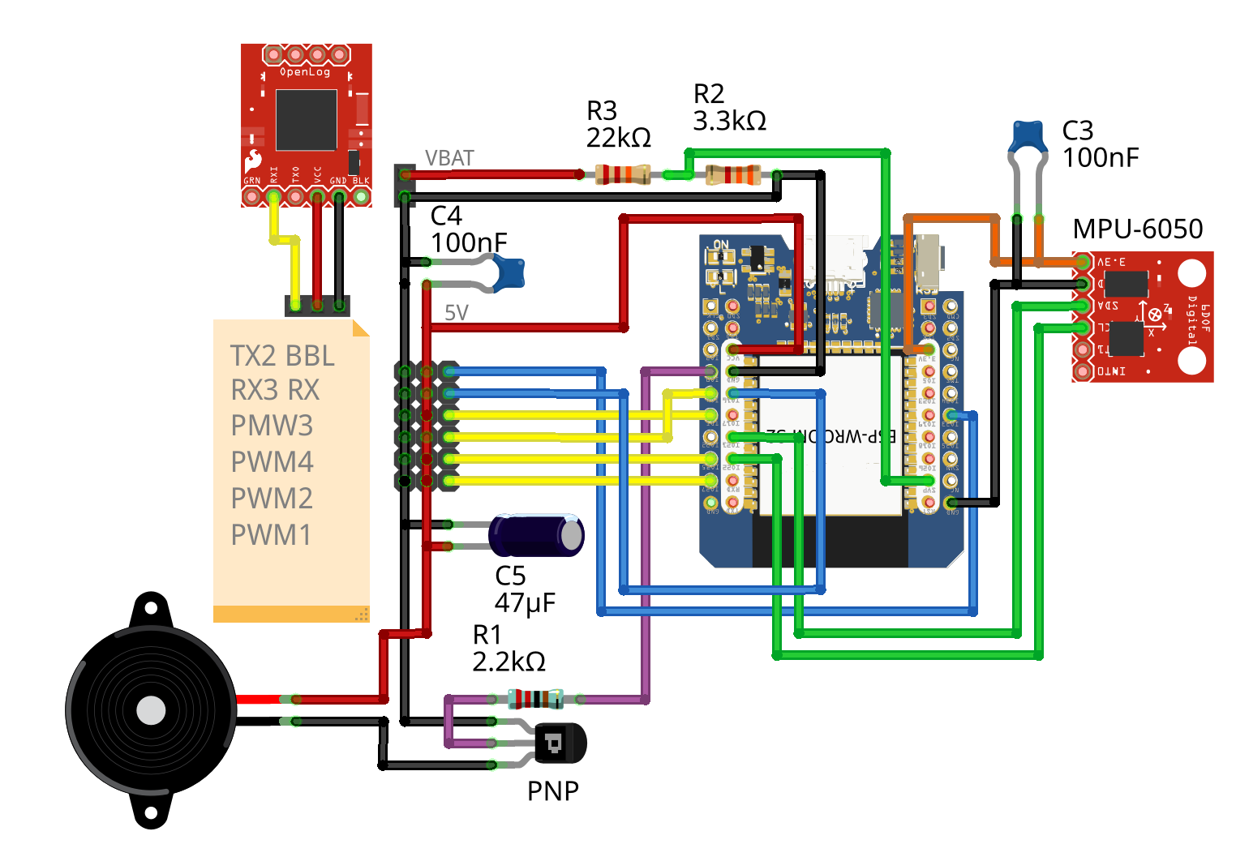
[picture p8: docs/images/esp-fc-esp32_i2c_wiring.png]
ESP-FC ESP32 I2C Wiring


## Example ESP8266 I2C MPU-6050 gyro

ESP8266 has limited ability to remap pins, use `get pin` command to list available options.

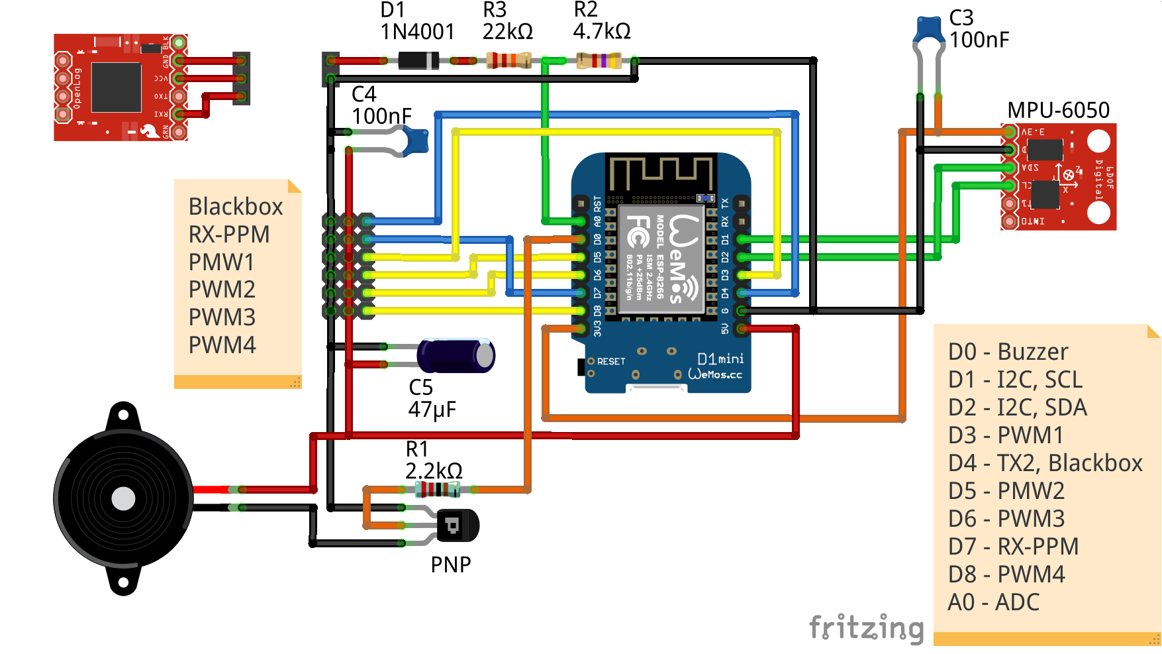
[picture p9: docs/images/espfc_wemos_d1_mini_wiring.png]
ESP-FC ESP8266 I2C Wiring


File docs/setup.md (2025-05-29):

# Setup

This page describe steps absolutly required to proceed before first flight.

## Connecting to Betaflight Configurator

Once you download and install [Betaflight configurator](https://github.com/betaflight/betaflight-configurator) you need to change few options first. Open configurator and go to **Options** tab, and then
1. Disable `Advanced CLI AutoComplete`
2. Enable `Show all serial devices`
3. Disable `Auto-Connect`

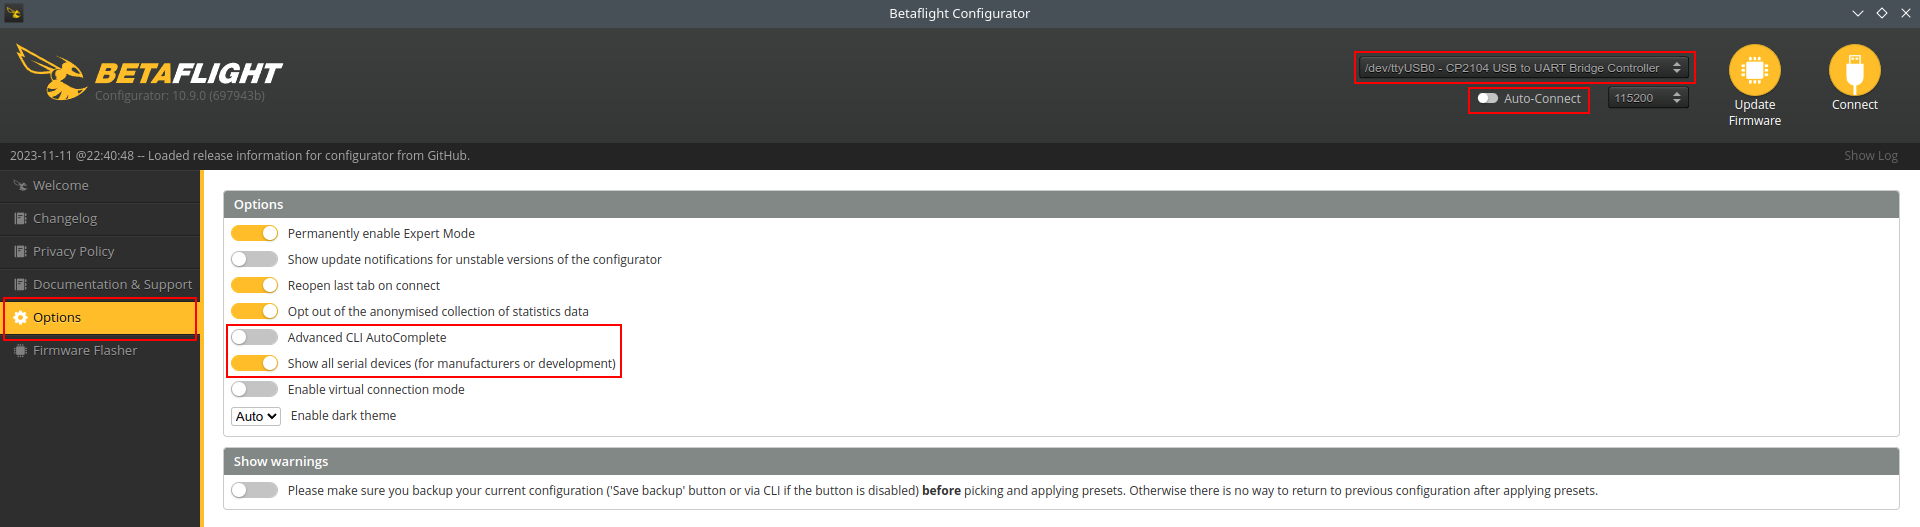
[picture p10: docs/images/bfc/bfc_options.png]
Options


Then select your device from list and click connect.

> [!NOTE]
> Not all functions displayed in configurator are avalable in firmware. The rule of thumb is if you cannot change specific option in Betaflight Configurator, that means it is not supported. It usually rolls back to previous value after save.

> [!NOTE]
> Leaving some tabs, especially CLI requires you to click "Disconnect" button twice, and then click "Connect" again.

## Configure wiring

Go to the `CLI` tab and type `get pin`. This command will show what pins are associated to specified functions. If you wiring is diferrent, you can make some adjustments here. For more details, see [Pin Functions CLI Reference](/docs/cli.md#pin-functions)

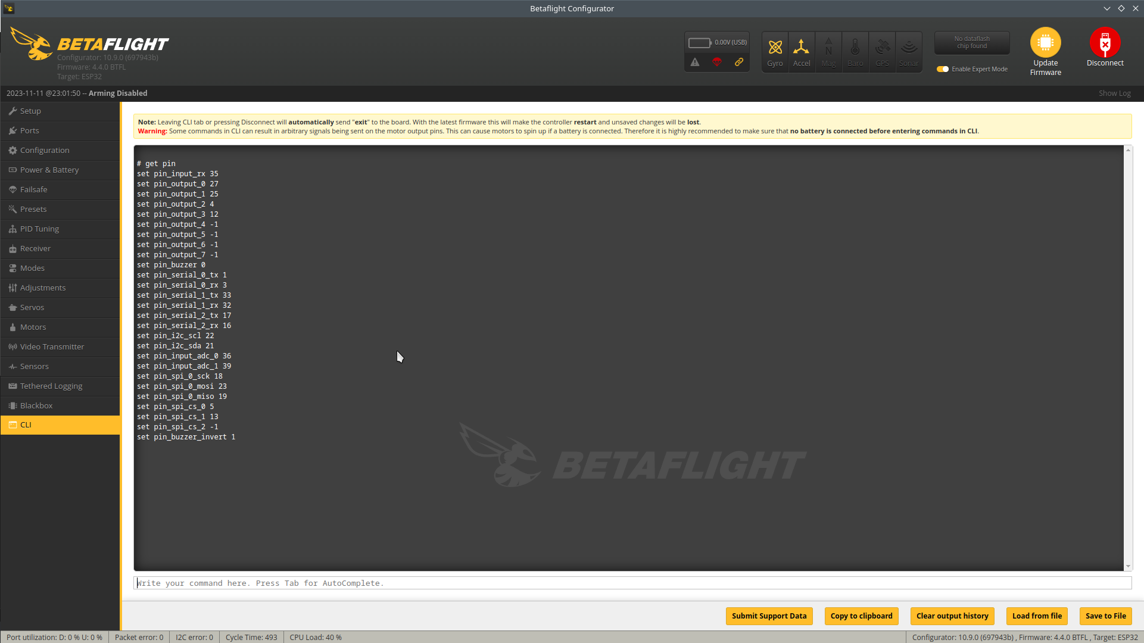
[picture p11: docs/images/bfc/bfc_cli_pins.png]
CLI Pins


## Gyro calibration

Go to `Setup tab`, make sure that your model is in horizontal steady state position. Then click **"Calibrate Accelerometer"** button and wait two seconds.

> [!CAUTION]
> Ensure that model in preview moves exactly in the same way as yours. If it is not the case, go to the `Configuration` tab, and configure `Board orientation` or `Sensor Alignment`

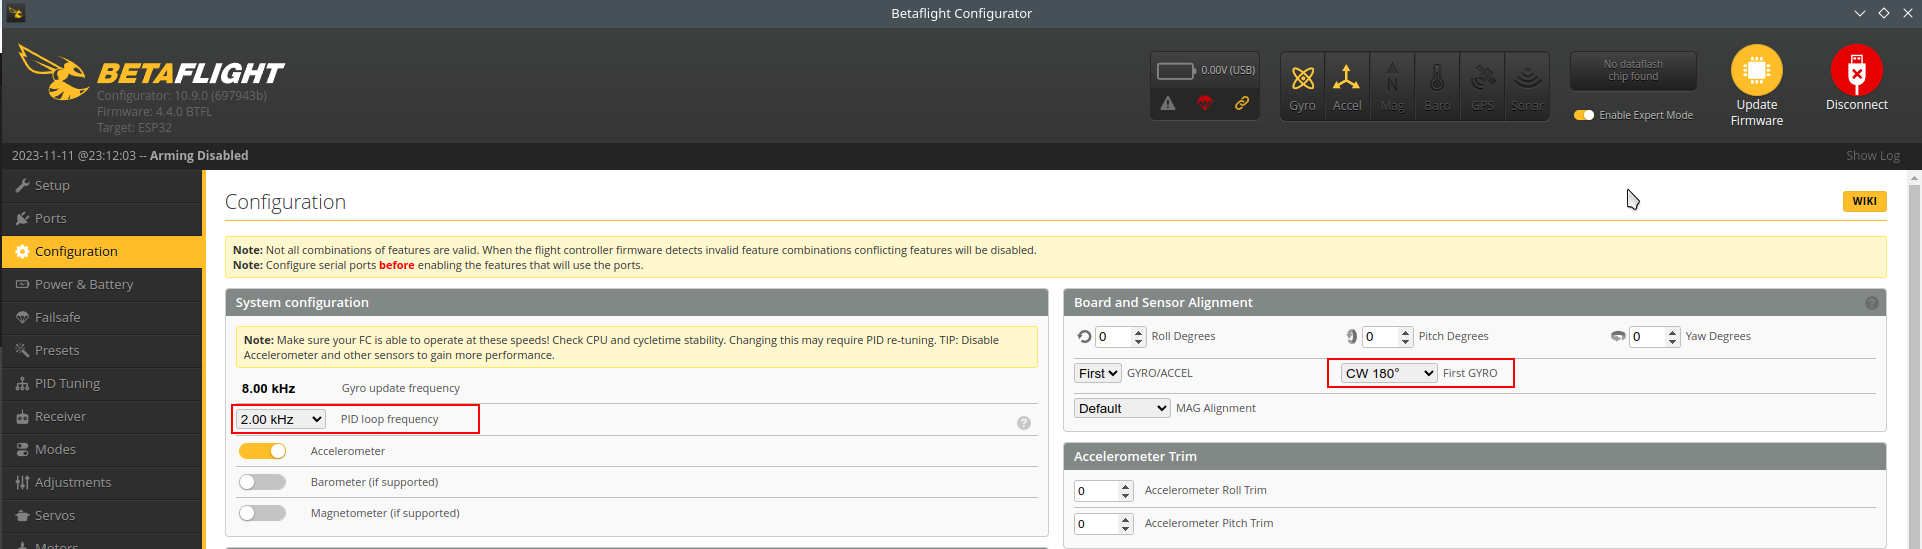
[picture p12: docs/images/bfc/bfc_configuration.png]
Sensor Alignment


## System configuration

In `Configuration` tab set `Pid loop frequency`. Recomended values are 1kHz to 2kHz. Keep eye on CPU Load displayed in bottom, it shoudn't exceed 50%.

## Receiver setup

If you want to use Serial based receiver (SBUS,IBUS,CRSF), you need to allocate UART port for it. You can do it in `Ports` tab, by ticking switch in `Serial Rx` column.

Then go to the `Receiver` tab, and select `Receiver mode` and `Serial Receiver Provider`.

To use ESP-NOW receiver, choose "SPI Rx (e.g. built-in Rx)" receiver mode in Receiver tab. You need compatible transmitter module. Read more about [ESP-FC Wireless Functions](/docs/wireless.md)

## Motor setup

In `Motors` tab you must configure

### Mixer

You can select mixer type here, this configuration depends on type of aircraft you are configuring. 

**Important!** If you build multirotor, you must ensure that

1. Specified motor number is connected to specified output and placed in specified position in your aircraft according to gyro orientation, presented on a picture.
2. Specified motor is rotating in correct direction according to image.

> [!CAUTION] 
> If these conditions aren't met, your quad will go crazy on the first start and may cause damage or even injury.

To verify that you can enable **test mode** and spin each motor selectively. To do that,
1. remove all propellers, 
2. connect batery,
3. click "I understand the risk...", 
4. move specified slider to spin motor.

If you are using any analog protocol (PWM, OneShot, Multishot), you also need to calibrate your ESCs here. To do that
1. click "I understand the risk...", 
2. move master sliders to highest value
3. connect battery
4. when escs plays calibration beeps, move master slider down to lowest value
6. escs should play confirmation beeps

> [!NOTE]
> Only Quad X supported at the moment. Motor direction wizard is not supported, you must configure your ESC separately. The easiest way to change direction is swapping motor wires.

### Motor direction is reversed

This option informs FC that your motors rotating in reverse order. This option desn't reverse motor direction. It has to be configured with ESC configurator or by swapping motor wires.

### ESC protocol

You can select here protocol according to that you ESC can handle. For multirotor it is recommended to use `DSHOT150` or `DSHOT300`. Older ESCs may not support digital protocols, in this case it is recommended to use `OneShot125` at least. `Brushed` protocol is for driving brushed motors through FET drivers.

It is not recomended to use `PWM` for multirotors.

### Motor PWM speed separated from PID speed

This option allows to separate PWM frequency. If your pid loop is set to 1k, but ESC can accept maximum 333Hz. PWM is limitted to 480Hz.

## Flight modes

Flight modes can be configured in `Modes` tab

### Arm

It is required to enable this mode to be able to fly. Armed quad cause that motors are spinning (unless Motor stop option is enabled).

### Angle

By default ACRO mode is engaged if none of flying mode is active. This mode enables self-leveling. In this case you control titlt angle of multirotor instead of rotationg rate. It affects only Roll and Pitch axes. Yaw axis behave the same way as in Acro mode.

### Air mode

Increases the range of control at extreme throttle positions. Recommended to enable, can be controlled by the same RC channel as Arm to get permanent behaviour. Activates, when throttle achive about 40% remains active until disarmed.

### Buzzer

Acitvates buzzer, for example to find lost model in high grass.

### Fail safe

Triggers Failsafe procedure.

## Blackbox

It is possible to collect flight data in two ways. Via `serial port` or with `onboard flash`

Onboard flash allows to store about 2.5MB of data. This is equivalent of 2-3 minutes of flight. It should be enough for tuning. 

If you need more, choose `Serial Port` and serial device like [D-ronin OpenLager](https://github.com/d-ronin/openlager) or [OpenLog](https://github.com/sparkfun/OpenLog). To configure it
1. In `Ports` select uart to generate stream and in Peripherals column select `Blackbox logging` on free port
2. Then in `Blackbox` tab select `Serial Port` or `Onboard flash` as `logging device`

> [!NOTE]
> Port speed from column `Configuration/MSP` is used, and the same speed must be used in logging device, _(this might be subject of change in a future versions)_.

Recommended settings

- To log with 1k rate, you need device that is capable to receive data with 500kbps.
- To log with 2k rate, you need 1Mbps

OpenLager can handle it easily. If you plan to use OpenLog, you might need to flash [blackbox-firmware](https://github.com/cleanflight/blackbox-firmware) to be able to handle more than 115.2kbps. Either 250kbps and 500kbps works well with modern SD cards up to 32GB size.

## Limitations

### Configuration tab

In Other features you can enable only `Dynamic Filter` and `SoftSerial`

`AirMode` is only available in modes tab. If you want to enable it permanently, use the same control channel as ARM.

### Failsafe tab

Only "Drop" Stage 2 procedule is possible

### Presets tab

Presets aren't supported, do not try to apply any of them.

### PID Tuning tab

1. There is only one pid profile and one rate profile
2. Feed-forward transition has no effect
3. Iterm-rotation has no effect
4. Dynamic damping has no effect
5. Throttle boost has no effect
6. Miscellaneous settings has no effect
7. Dynamic Notch works from 1k pid loop, but is not displayed in configurator if this speed is configured, to reconfigure switch pid loop to 2k.

Besides that most of Betaflight principles can be applied here according to PID and Filter tuning. But keep in mind, very aggresive tunnig tips aren't recommended to apply and might lead to diferrent results.

### Receiver

1. Not all protocols are implemented, currently only PPM, CRSF, SBUS, IBUS
2. NoOnly CRSF telemetry and and rssi_adc
3. RC deadband applies to RPY, no separate Yaw deadband

### Modes

Add range works only, no add link

### Adjustments

Not implemented, for replacement you can use [pid scaler CLI](/docs/cli.md#scaler-configuration)

### Servos

Not Implemented, for replacemnt you can use [output cli](/docs/cli.md#output-channel-config) to change output protocol and rate.

### Motors

No 3D features, only Quad-X Mixer

### Video transmitter

Not yet implemented, work in progess

### OSD

Not implemented, but MW_OSD should works via serial port and MSP protocol.

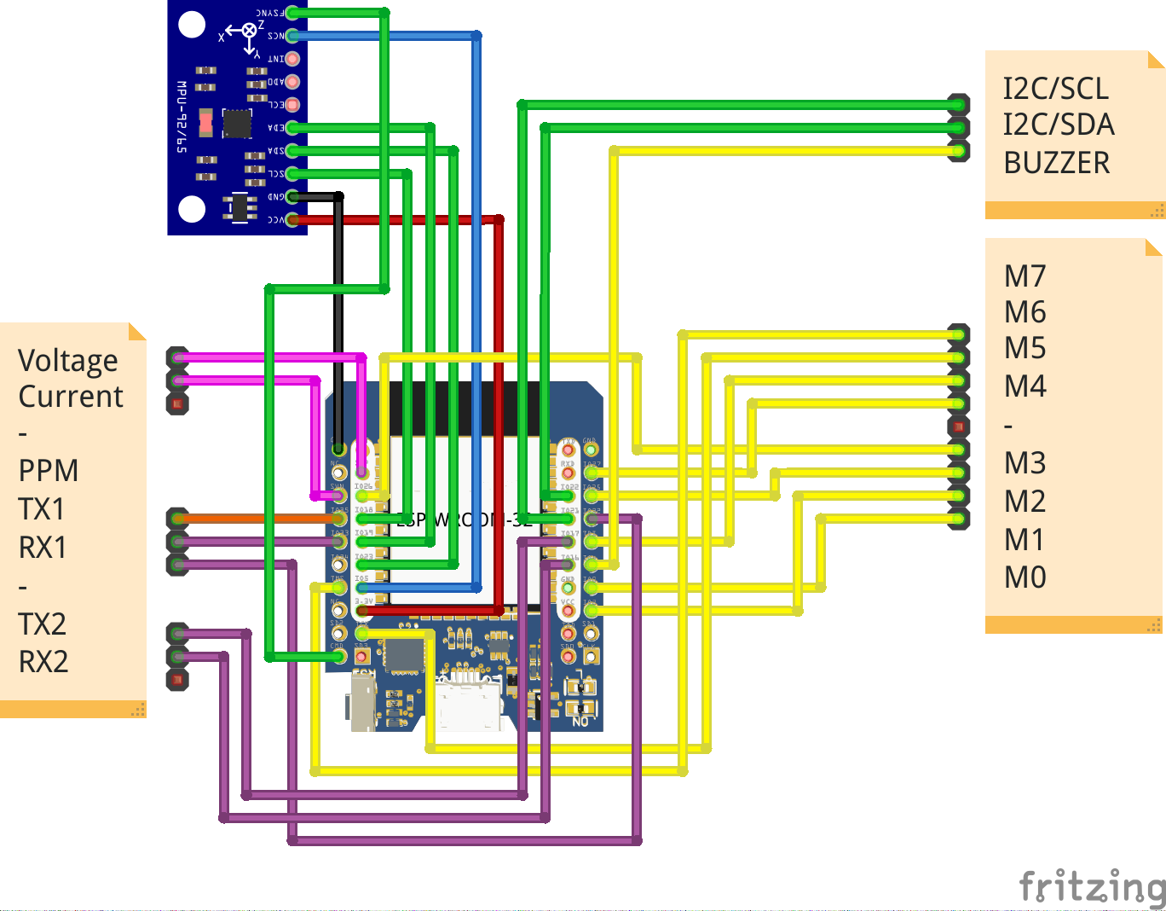
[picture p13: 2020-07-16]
docs/images/espfc_wemos_mini32_wiring.png

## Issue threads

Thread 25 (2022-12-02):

Error Compiling

RDSpt, 2022-12-02:
Hi,

First of all thanks for this project, I'm trying to tinker around and upload your code into a nodeMCU v3 (esp-8266). Although, I'm having some issue when trying to compile the code, and can't figure what's wrong.

The errors seems to be in the Debug.h file. Possibly some issue with my environment, but any help is thanked.

I'm leaving here the logs in case you want to check it out.

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

Thanks

benvdbergh, 2023-03-20:
Hi,

I'm having the exact same issue. But I noticed that the build works perfectly if you build for the esp32 boards.

For the esp8266 boards the Stream.h is not included in the Arduino.h file. Might have to look for an 8266 alternative for the Stream library?

Closed 2023-04-01.

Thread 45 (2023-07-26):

Esp32 not detecting gyro

Shally1986, 2023-07-26:
I have flashed the esp32 firmware to esp32 nodemcu and wired up mpy6050 as per the image on the docs . But in betaflight there is no gyro .

I think the image is for spi connection and mpu6050 is i2c . Where do I connect mpu6050 on esp32 ?

AutoPlantBali, 2023-07-27:
mpu6050 use i2c only..
esp32   | mpu6050
D22      | SCL
D21      | SDA

Shally1986, 2023-07-27:
Thanks it works . I'm using esp 32 wroom . Pid loop is fixed at 1K how to make it 8K

AutoPlantBali, 2023-07-27:
use mpu6500 or mpu9250 support spi

Shally1986, 2023-07-27:
Thanks for the information .

Awesome project . I'm trying to build a brushed flight controller .

On Thu, 27 Jul, 2023, 2:41 pm Auto Plant Bali, ***@***.***>
wrote:

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

Shally1986, 2023-07-27:
Issues closed

rtlopez, 2023-07-27:
Hi @Shally1986 @AutoPlantBali,

actually not quite, I checked it and I2C does not work on esp32. So I prepared fix and just merged to master branch. If you want to test it, flash device directly from this branch, I'm going to prepare new release soon.

MPU6050 works only on I2C bus.

Also keep in mind that wiring for esp32 might not be up to date, werify your pinout with CLI output command `get pin`, especially motor output. On ESP32 you can remap most pins according to your needs too.

Shally1986, 2023-07-27:
Post connecting mpu6050 to i2c I'm able to detect gyro and accelerometer in
betaflight .

How do I flash directly from branch ? Do i need to compile ? Could you help
me with the firmware or details on compilation and pin out for pi pico .

Thanks
Kushal Sahota

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

rtlopez, 2023-07-27:
@Shally1986 I forgot, you can try this build https://github.com/rtlopez/esp-fc/actions/runs/5679139675

RP2040 is experimental, and because of lack FPU, do not perform fast. I have not yet prepared the upload process without the development environment.

Closed 2023-07-27.

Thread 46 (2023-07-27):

wireless mode AP for softserial?

AutoPlantBali, 2023-07-27:
I try to edit this code
https://github.com/rtlopez/esp-fc/blob/add5b6ba346f0be9034b2920dda7488fdc7a1de8/lib/Espfc/src/Wireless.h#L33

with this code:

WiFi.persistent(false);

        if(_model.config.wireless.mode == WIRELESS_MODE_AP){
          WiFi.mode(WIFI_AP);
          status = WiFi.softAP(_model.config.wireless.ssidAp, _model.config.wireless.passAp);
          _server.begin(_model.config.wireless.port);
          _model.state.serial[SERIAL_SOFT_0].stream = &_adapter;
          _model.state.localIp = WiFi.softAPIP();
          _initialized = true;
          _model.logger.info().log(F("WIFI EV")).log(F("IP")).logln(WiFi.softAPIP());
        }else{
          WiFi.mode((WiFiMode_t)_model.config.wireless.mode);
          status = WiFi.begin(_model.config.wireless.ssid, _model.config.wireless.pass);
        }

on CLI set AP mode:
set wifi_mode AP
set wifi_ssid_ap autoplantbali
set wifi_pass_ap autoplantbali
set wifi_tcp_port 1111

setup pc windows/linux using virtual serial:
https://hackaday.io/page/1304-virtual-serial-port-tunnel-to-use-with-esp-link

betaflight configurator can connect with esp32 and android betaflight configurator with settings: tcp://192.168.4.1:1111

maybe plus 1 input button to turn off and on access point mode. so there is no need to connect using a USB cable and 3 serials can be fully used.
I see the wifi code is connected to softserial, what impact will it have?

rtlopez, 2023-07-28:
Hi,

Thanks for your comment.

I implemented it as proof-of-concept, but testing shows, that it consumes a lot of processing time which block PID loop. It wasn't on my priority list later. Definately I do not recommend to have this option enabled while arming. There is no any signity check at the moment. Technically it should be enough for configuration purpose or maybe for OTA firmware upgrade.

You can also start AP on your phone and you should be able to check assigned IP on your android device instead starting AP on ESP. Access point mode provokes more communication, because the phone tries to get access to the internet through ESP, then it floods the device with lots of requests from its applications.

I don't get why you mention about virtual serial, while it is not necessary because BF configurator can connect to tcp directly. Last time I tested it on v10.7 IIRC.

By input button do you mean to use GPIO pin to enable or disable wireless? But as it requires additional hardware, I'd consider to control this function with spare RC channel.

Exposing as soft serial allows to control what functions are enabled on this data stream. I do not see any negative impact here.

According to code you presented, it woud be better to move some parts to wifi event callback and handle `SYSTEM_EVENT_AP_STAIPASSIGNED` and `SYSTEM_EVENT_AP_STOP`, especially:
```cpp
_model.state.serial[SERIAL_SOFT_0].stream = &_adapter;
_model.state.localIp = WiFi.softAPIP();
```

If I found more time I'll play with it bit more.

AutoPlantBali, 2023-07-29:
Hi,
Thank you for replying and explaining in detail for me.

I have tried STA and AP modes, in STA mode there is more delay when connected to the betaflight configurator. if AP mode blocks PID loop maybe after arming auto turns it off.

after I try it can directly connect to tcp directly. thanks for the info, I usually use virtual serial to program Arduino via esp bridge.

wifi event callback
when connected to AP:
I WIFI EV SYSTEM_EVENT_STA_WPS_ER_PIN
I WIFI EV SYSTEM_EVENT_AP_STOP

when disconnected to AP:
I WIFI EV SYSTEM_EVENT_AP_START

this is the response that appears when rebooting via cli

Closed 2023-07-29.

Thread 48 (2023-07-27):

Brushed motor test

Shally1986, 2023-07-27:
On esp32 wroom board , mpu 6050 on i2c , elrs . Gyro accelerometer and elrs receiver all detected on betaflight .

I hav connected pin out 4 to brushed motor driver (fet ) . But on motor test no motor spool up . I hav connected battery to the motor fet and pin out 4 to pwm input .

Is there any specific setting for brushed ?

rtlopez, 2023-07-27:
Hi, there is new release https://github.com/rtlopez/esp-fc/releases/tag/v0.2.0-alpha2 where issue with brushed PWM should be fixed. Let me know if it helped.

Shally1986, 2023-07-28:
Hello ,

It didn't help but I'm not sure if it's software or hardware problem . I was able to run the motors on Arduino code using pwm . I will recheck again if the fet got fried or something . Do you have any schematic for brushed if you have tried ?

AutoPlantBali, 2023-07-29:
via cli in betaflight configurator:
use this command
# get pin_output
set pin_output_0 27
set pin_output_1 25
set pin_output_2 4
set pin_output_3 12
set pin_output_4 -1
set pin_output_5 -1
set pin_output_6 -1
set pin_output_7 -1

please check the vgs of the mosfet you are using.
I tried on pin 4 and it runs normally
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

mosfet brushed schematic:
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

Shally1986, 2023-07-29:
I will check and get back . Another stupid question . It will work with fets only or can use h bridge drivers ?

AutoPlantBali, 2023-08-07:
why use h bridge?, you need 2 pins to control 1 motor

Shally1986, 2023-08-07:
I think I do not have the correct mosfets and ordering them would take a
while . I have couple of lightweight tb6612fng motors drivers ( h bridge )
. As per my understanding h bridge is needed , if motors need to run both
direction . Most brushed flight controller use MOSFET but there were a few
which used h bridge and also supported turtle mode .

On Mon, 7 Aug, 2023, 5:33 am Auto Plant Bali, ***@***.***>
wrote:

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

Closed 2023-10-11.

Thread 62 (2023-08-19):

Not arm my quad

skimans, 2023-08-19:
Hi
i have install last version of firmware for my ESP32 but when i connect battery not arm the quad.
I use MPU6050 and my radio is Flysky I6.

how i can solve ?

thanks
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

rtlopez, 2023-08-19:
Hi @skimans,

It seems that you gyro is very noisy and callibration not finishing. Ensure your model is not moving when you connecting it. Consider mounting it with using adhesive tape and solder with flex cables instead direct soldering. If it won't help, you should look for replacement.

skimans, 2023-08-19:
Hi
I have solved.
Was a problem on my gyro/acc.
I have used GY87 but not work becouse i have used 3,3 volt.
Now i have used GY521...normal MPU6050 and now work fine

One question . It's posible have a version firmware for Inav ?

Thanks much.
And my complimentes for this your wonderful project.

Stefano

Il sab 19 ago 2023, 16:10 rtlopez ***@***.***> ha scritto:

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

rtlopez, 2023-08-19:
What do you mean by
> firmware version for Inav?

This firmware is neither Betaflight nor Inav. It is only partialy compatible to work with Betaflight-configurator. Not all features are available here.

Closed 2023-08-29.

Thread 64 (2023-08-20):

Change motor spinning direction

Lisanderl, 2023-08-20:
Hello!
I've tried to use CLI ti change motor spinning direction from N to R (set output_0 M R 1000 1500 2000). But It has no effect.
I also try to play with limits like change 1000-2000 to 2000-1000 and have same result.

Maybe I do something in a wrong way ?

rtlopez, 2023-08-21:
Hi @Lisanderl,

this function is intended to reversing servos, not motors. To change motor direction you have two options
1. use spare fc or 4way interface to programm ESC, this firmware doesn't support this function yet
2. swap two motor wires

Lisanderl, 2023-08-21:
Oh, I see. Going to swap motor wires, thanks!

Closed 2023-08-21.

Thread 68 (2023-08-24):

Quad roll forward

skimans, 2023-08-24:
Hi
i have install firmware and setup it.
When i test it after armed and try to fly the quad roll forward and is not stable.
I have used module GY-87 but also with only MPU6050 i have same problem.
How i can solve ?
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

bsvdoom, 2023-08-25:
i think your gyro needs to be in the geometric center

rtlopez, 2023-08-25:
Hi @skimans

The amount of information you've provided is too small for me to give you any meaningful advice. Could you write more about your setup? What battery, how mounted, what motors, propellers, esc, protocol, loop rate, flight mode, etc.

First of all, you need to check the endpoints again, with particular emphasis on receiver. With the sticks centered, the channels should indicate exactly 1500.

Your setup in the picture looks quite non-standard, and the default parameters are oriented to 5-inch models. So most likely PID tuning will be needed. In such situations, the blackbox logger is an underrated tool. But before you get to that, you should first take care of the mechanical-electrical design. The gyro can't just be soldered like that, it should be glued firmly to the frame, preferably with a damping tape. Also, take care of filtering the power supply, I don't see any capacitors in the pictures.

skimans, 2023-08-27:
Hi @rtlopez

i use battery 4s Liion. The battery uis connected to PDB the have a BEC of 5V.
This 5V are connected di VCC pad of ESP32.
The gyro/acc is MPU6050 (module GY-521...i can connect also GY-87 that have also baro BMP085...but i prefer GY-521 for 3.3 volt used and not 5v for GY-87).
The motors are 2212-912KV mounted on frame F450. The props are 8045.
Flight mode i use Acro or Angle mode (you tell me before that if i dont have Angle the is Acro).
Loop rate...mmm..i dont know what's..i send to you scheenshot.
The receiver is FS-IA6B with radio Flysky I6.

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

skimans, 2023-08-28:
one particulary....i dont have put the resistors and other electrical components..
can be this the problem ?

rtlopez, 2023-08-28:
Hi @skimans

> i use battery 4s Liion. ... The motors are 2212-912KV mounted on frame F450. The props are 8045.

What is total weight including battery? I suppose that the power to weight ratio can be too small and you might need to increase PIDs. With blackbox log it would be a lot easier to identify if issue comes from filtering or PID gains.

> Flight mode i use Acro or Angle mode (you tell me before that if i dont have Angle the is Acro).

On screenshot I don't see Angle mode configured, so you are using Acro. Keep in mind that in this mode your model won't back to horizontal automatically and you need to do using sticks. In this mode you control only angular rate of quad. I'm not sure your flying skills.

> Loop rate...mmm..i dont know what's..i send to you scheenshot.

I meant `Frequenza di loop del PID`, 1kHz in your case.

I need to ask few more questions:
1. how long are you able keep model in the air?
2. how fast does it roll?
3. are you able to share a video?

Few things comes to my ming that can be checked
1. ESC calibration, have you done it?
2. Center of Gravity - ensure your battery position so that when you keep the model in the middle, it doesn't pull to either side.

If above hints won't help, you can try to increase `pid_iterm_limit` parameter through CLI.

skimans, 2023-08-30:
The total weight battey included it's about 2 kg. I use your PID set in your firmware.
Today i have set and use also Angle mode but not change the situation.

The quad not flight in the air becouse when i put gas the quad roll forward.
Roll forward very fast.
When it's posibile i proceed to do a video.

The sound of music of Esc calibration (Motor tab) is not the normal sound.
The position of battery is in normal position respecting the center gravity.

I saw that the stick of radio are much sensitive, infact if a move little rear the quad roll rear, if i move little left quad roll left.

bsvdoom, 2023-08-30:
2kg?? what? are you sure?
angle should hover, try set the gyro/accel to 180deg:
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

skimans, 2023-08-30:
2 kg all the quad...all included. It's a F450 frame.

i try set the gyro/accel to 180deg..but if i remember not memorized other value, but this evening a try.

thanks for now!

rtlopez, 2023-08-30:
@skimans This symtomps looks like wrong gyro orientation or wrong motor order. Go to the setup tab, and ensure that model in configurator moves exactly in the same way as you do, if not try diferrent algnment options in configuration (as @skimans suggest). Then go to the motor tab, and ensure correct motor order. Each motor has to be placed in correct position according to front direction. Then Take of props and spin each motor separately in test mode to verify. Ensure that they rotetes in correct direction.

skimans, 2023-08-30:
gyro orientation can be the problem becouse many time i saw that the quad in Setup tab not move correctly....but this also if i change orientation. It's incredbile this. But i try another time to change orientation.
I have also check in Motor tab the position and rotation of the motors and is OK.
But i check another time.

skimans, 2023-08-30:
> 2kg?? what? are you sure? angle should hover, try set the gyro/accel to 180deg: 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

hi @bsvdoom

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

when i select CW180 and after Save and Restart....not save 180CW.
I can change using CLI ?

rtlopez, 2023-08-30:
Hi @skimans

looks like bug in MSP, configurator does not show correct value, but it is saved after change. You can verify in CLI with command `get align`, then you should see
```
set gyro_align CW180
set accel_align CW180
```
ensure that both accel and gyro have same alignment.

eventually you can try this commands in CLI.
```
set gyro_align CW180
set accel_align CW180
save
reboot
```
but ensure later that this settings persists at the end.

Your rates are way to low, 20 deg/s make aircraft uncontrollable. At the beginning I recommend 100 or even 200 at least. These values are still very conservative. Most users use 400-600 or even higher. Bu keep in mind, they are used in Acro mode only.

You quad is quite heavy, and it might be underpowered. So after first flights if quad is not responsive you can consider increase PID, using "master multiplier" slider. If you notice that it shakes, that means that PIDs are to high.

skimans, 2023-08-31:
hi
this evening i have tried to use STM32F411 board with Inav custom firmware created from me and the quad work fine.
Then there is not a hardware problem.
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

rtlopez, 2023-08-31:
Hi @skimans , there is new release https://github.com/rtlopez/esp-fc/releases/tag/v0.2.0-alpha5
setting sensor alignment is fixed there.

skimans, 2023-09-01:
hi @rtlopez
thanks but i think is not problem of alignment of gyro/acc.
I have also modified this using CLI before.
But this evening i try.

AutoPlantBali, 2023-09-01:
hi @skimans
MPU6500 support I2C and SPI connection.
you can choose one of them, SPI connections are faster than I2C.
If you use the ESP8266 board it only supports I2C

rtlopez, 2023-09-01:
Hi @skimans
Yes, MPU6500 suppors either I2C and SPI. I recommend to use SPI on ESP32 if possible. In that case use spi wiring scheme.

skimans, 2023-09-01:
Finally flyyy!!!

I want ask if is posible set Yaw Deadband becouse now is not posible save it.
It's in Receiver tab.

thanks much @rtlopez @bsvdoom @AutoPlantBali

skimans, 2023-09-01:
one problem now is that go drift to right...

rtlopez, 2023-09-01:
Hi @skimans

> Finally flyyy!!!

Good to hear that it flies, one more aircraft with esp-fc ;)

> I want ask if is posible set Yaw Deadband becouse now is not posible save it.

RC deadband is applied to yaw axis too.

> I have saw also that the motors are little hot after 1 minute of fly. But i think it's a problem of PID..right ?

There is no easy answer. The best way to solve issues with hot motors is to record blacbox log to see and understand what actually going on inside firmware. Without that we can only guess what setting we can change and test in the air to verify if it help. Most tips for betaflight that you can find on the internet should works in espfc too. So try google "betaflight hot motors".

> one problem now is that go drift to right...

What do you mean drift? in which mode? Have you calibrated accelerometer? Note that there is no any navigation/position hold/GPS mode, so it is normal that your quad drifts a little. Also blackbox log is appreciated here to solve this issue. Eventually try google "betaflight quad drift" or "betaflight pid tuning"

> other problem is that if i enter in CLI appear many words....

Show it to me.

skimans, 2023-09-04:
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

i have solved partially use RC Deadband. It's also problem of stick of radio, becouse when i move of left or right the stick on the tab receiver i saw value about 1530 or 1470....and not 1500.
But using RC Deadband now is best.

thanks

skimans, 2023-09-06:
hi @rtlopez in this video you can look what happen when i enter in CLI

https://github.com/rtlopez/esp-fc/assets/78317991/d4c5d97e-dafb-49f9-adb3-3048bb3c7ea5

this happen only in pc of my home.
In other pc work fine and i not see this words.

rtlopez, 2023-09-06:
Hi @skimans , thanks for your report. At the bottom-right there is "save to file" button. Can you collect some messages, save to disk and attach here. Also tell me which firmware version exactly do you use (connect to other PC and type `status` or `version` in CLI)

If it happes on one PC but not on the other it may suggest power issue. Try diferrent cable or diferrent USB port. Disconnect any other devices connected through the USB if possible.

AutoPlantBali, 2023-09-06:
hi @skimans
From the video it can be seen that there is no gyro sensor detected in SPI and I2C... and it will repeat itself when checking the gyro bias, maybe there is a problem with the USB power on your computer.

skimans, 2023-09-06:
Hi @rtlopez @AutoPlantBali
i have solved connecting the gyro/acc.
With gyro/acc i dont have problem in CLI.
thanks much

rtlopez, 2023-09-06:
@skimans what was that?

rtlopez, 2023-09-06:
@skimans I mean, how did you solved it? Maybe someone else will have a similar problem, so here will fin solution.

skimans, 2023-09-06:
@rtlopez In my last video i have connected ESP32 with cable USB directly to pc (without gyro/acc) and i haved the problem of CLI.
For solve it i have connected gyro/acc (MPU6500...SPI) to ESP32 and connected ESP+gyro/acc to pc with cable USB now work in CLI.
I hope that you understand.

rtlopez, 2023-09-06:
@skimans now it's clear, thanks :)

Closed 2023-09-09.

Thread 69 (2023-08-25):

ESP32-C3 support?

bsvdoom, 2023-08-25:
I started to make a new target for the [ESP32-C3](https://docs.ai-thinker.com/_media/esp32/docs/esp-c3-32s-kit-v1.0_specification.pdf).

Now betaflight can connect and it looks like it works, but some lines produce errors and needs to be rewritten as I saw, but I lack the knowledge to do so.. (now they are just commented out to see if it works):

Can you help me fix these please, do you have an idea how to do this, should I make a pullrq into a new branch?
Thanks!

AutoPlantBali, 2023-08-25:
i'm not sure it will run well with limited number of IO pins and only have 1 core

bsvdoom, 2023-08-25:
the esp8266 has less pins and 1 core as well, and it runs on that too..

bsvdoom, 2023-08-25:
Some more work, and all options seems to work in betaflight, but:
-Gyro slowly rotates to the right at 5dec/sec
-Motor outputs does not seem to work correctly
-Cannot set the PID cycle above 0.5kHz
-If I enable the baro, it freezes on the next boot after the message "I I2C DETECT MPU6050"

rtlopez, 2023-08-25:
@bsvdoom Thanks, that looks pretty decent. If you could do a PR, I'd put some comments. Nevertheless, the fact is that in the case of the C3 we have fewer IO pins available than in the ESP8266 IIRC.

bsvdoom, 2023-08-27:
@rtlopez As far as I know ESP8266 has 17 (ESP12-F has 9), and ESP32-C3 has 21 available IO pins.
I made the PR #70, so I close this issue now, thanks!

Closed 2023-08-27.

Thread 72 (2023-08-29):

Gyro issue? (GY-521)

bsvdoom, 2023-08-29:
So I connected a GY-521 I2C to a Wemos D1 mini.

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

[And the yaw rotates slowly..](https://www.youtube.com/watch?v=SNSHea0lUOM)

Tried with all PID loop freqs, 3.3V and 5V, and I used the latest release, can it be an issue with my gyro, can someone confirm it works fine?

rtlopez, 2023-08-29:
Hi @bsvdoom

go to the CLI, type `reboot` and wait untli you see a line `I GYRO CAL...`. Ensure, that gyro is not moving at that time. then place result here.

You can try to slow I2C bus with commands
```
set i2c_speed 700
save
reboot
```
you can try eventually 500 or 400.

bsvdoom, 2023-08-29:
```
15:42:14.638 -> # reboot
15:42:14.638 ->
15:42:14.638 ->  ets Jan  8 2013,rst cause:2, boot mode:(3,7)
15:42:14.638 ->
15:42:14.638 -> load 0x4010f000, len 3424, room 16
15:42:14.638 -> tail 0
15:42:14.638 -> chksum 0x2e
15:42:14.638 -> load 0x3fff20b8, len 40, room 8
15:42:14.638 -> tail 0
15:42:14.638 -> chksum 0x2b
15:42:14.638 -> csum 0x2b
15:42:14.638 -> v00061dc0
15:42:14.638 -> ~ld
15:42:14.702 -> �
   �n� r��n|�
l
�
l`
b
b r  l�nB�n
l` �
r l�l �

 I UART 0 0 1 115200 -1 -1

15:42:14.702 ->  I F_CPU 160000000

15:42:14.702 ->  I EEPROM loaded

15:42:14.702 ->  I I2C SETUP 4 5 700 1

15:42:14.702 ->  I I2C DETECT MPU9250 0

15:42:14.702 ->  I I2C DETECT ICM20602 0

15:42:14.831 ->  I I2C DETECT MPU6050 1

15:42:14.831 ->  I I2C DETECT HMC5883 0

15:42:14.831 ->  I I2C DETECT BMP280 0

15:42:14.831 ->  I I2C DETECT BMP085 0

15:42:14.831 ->  I MOTOR CONF 1 0 480 1

15:42:14.831 ->  I MOTOR PIN 0 0

15:42:14.831 ->  I MOTOR PIN 1 14

15:42:14.831 ->  I MOTOR PIN 2 12

15:42:14.831 ->  I MOTOR PIN 3 15

15:42:14.831 ->  I GYRO INIT MPU6050 0 8000 1000 1000

15:42:14.831 ->  I ACCEL INIT MPU6050 501 1995 1

15:42:14.831 ->  I FUSION MAHONY 50

15:42:14.831 ->  I RX PPM 13 1

15:42:43.069 ->  I GYRO BIAS -0.00 0.00 0.00
```

After this if i connect to betaflight, it rotates only 1deg/sec, but gyro does not react if i rotate the gy-521.
After reconnecting the Wemos, the same happens as before.

OK, so it was the module,
THIS ONE PRODUCES ERRORS:

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

THIS ONE WORKS FINE: (immediately biased, no yaw roll)

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

rtlopez, 2023-08-29:
Hi @bsvdoom

```
15:42:14.831 ->  I RX PPM 13 1
15:42:43.069 ->  I GYRO BIAS -0.00 0.00 0.00
```
definately there is something wrong with this gyro. This log shows, that calibration took about 30s, and returned 3x0.0. Normally it should take 2 seconds and bias should lay around +/- 5.0 for each axis.

Closed 2023-08-29.

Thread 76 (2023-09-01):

Make this into a real FC

bsvdoom, 2023-09-01:
So I was thinking, if it is possible/favorable to make an esp32 chip based FC?
If its made with open source in mind, clones can exist, so it would not be a real "product", like ESP-CAM.

Pros:
-now iNav has an ESP32 target too
-it could be incredibly cheap opposed to stm32 based ~$60 FCs
-all chips can fit on one side
Cons:
-VTX will never happen on this chip

@rtlopez What are your thoughts on this?
Thanks!

skimans, 2023-09-02:
@bsvdoom Vtx can connected in Softserial port and GPS in RX1 TX1.
With Betaflight there is also GPS_rescue for recover the quad.
Sure ..Inav is a best solution for long and stabilized range.

rtlopez, 2023-09-02:
Hi @bsvdoom, the market is already saturated with similar solutions and it will be extremally difficult to succeed both in terms of cheapness and functionality. It all depends on how many people will be willing to invest in software development and board production. I don't think that boards would be significantly cheaper. This project is not oriented towards the commercial market, at least for now ;)

bsvdoom, 2023-09-03:
Hi @rtlopez, actually I did not found a lot of products for this use case, only the [ESP-Drone](https://www.aliexpress.com/item/1005005695006370.html).
I thought it can be ridiculously cheap as the ESP chip is well under $1, also the MPU6050 is $1 (especially in lager quantities), but I guess the PCB manufacturing process and so the price of it is the game breaker here. :(
Anyways, thanks for the response, if you change your mind in the future, I will be more than happy to help.

BTW I will release a PCB project so one can CNC and assemble at home easily an FC for this project, like this prototype:
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

Cheers!

Closed 2023-09-03.

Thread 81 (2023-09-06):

Baro BMP280 not recognized

skimans, 2023-09-06:
Hi friends
i have install baro BMP280 with connection 3.3v GND SCL(I22) SDA (I21) but not work.
I have connected the 3.3V and GND directly to 3.3V  and GND of MPU6500.

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

rtlopez, 2023-09-06:
HI @skimans please specify "not works". How do you verify it? Double check connections. Go to the CLI, type `status` command, and then `reboot` and paste result here. Also you can flash board with arduino i2c scanner sketch to verify if device responds at `0x77` address. Keep in mind, that baro reading is only informational, can only be logged to blackbox, it is not used in any flight mode, so altitude hold is not possible yet.

skimans, 2023-09-07:
hi @rtlopez the external module baro BMP280 not recognized on the yellow panel icons .
Now i checked with Arduino and this is the result:

Scanning...
I2C device found at address 0x76  !
done

rtlopez, 2023-09-07:
Hi @skimans This module documentation says
> The I2C interface uses the following pins:
• SCK: serial clock (SCL)
• SDI: data (SDA)
• SDO: The I2C address decides the pin. If SDO connects to GND(0), the address is 0x76, if it connects to VDDIO(1), the address is 0x77. In this module, we have connected it to VDDIO, so the address should be 0x77.
• CSB: Must be connected to VDDIO to select I2C interface.

Is anything connected to SDO pin? This module supports SPI, you can share bus with gyro, only need separate CS line. Connect CSB pin to baro_cs pi, 13 py default.

skimans, 2023-09-07:
i have saw that if i use external module GY-87 ...that include also baro BMP085...the baro is recognized and work fine.
Single external BMP280 is not recognized.

skimans, 2023-09-07:
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

the SDO is free. anything connected.
i dont understand what can i do for have 0x77 and connect it to I2c.....VDDIO ??

bsvdoom, 2023-09-07:
You should generally try and solve these problems first yourself, by googling and trying solutions.
The majority of problems you declare here has nothing to to with esp-fc, just wrong wiring and general electronic failures.
Do not get me wrong, we are here to help, but spamming the issues before you spend enough time to try to solve it yourself, wont help you in the long-terms.

Now they specifically told you what is the problem and what to do in this case (which you could've also lookup in forums, or in the BMP280 datasheet), that CSB and SD0 pins have to be connected to VCC (3.3V).
Here is a picture to make this clear:
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

skimans, 2023-09-07:
@bsvdoom i have already speand my time to search in Google. If i ask here it's becouse i dont have found other solutions.

Thanks you!

rtlopez, 2023-09-07:
@skimans take multimeter and ensure if there is no short-circuit to GND or other pin. If there isn't, you can safely connect it to 3.3V, otherwise you can burn LDO or even chips on boards. Normally there shoud be pull-up resistors on SDO and CSB, but it is not guaranted. Your BMP listen on 0x76 address just because SDO level is 0.

skimans, 2023-09-07:
@rtlopez now you must work for add GPS :)
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

bsvdoom, 2023-09-07:
> @rtlopez now you must work for add GPS :) thanks much!!

I am sure if you donate to him he will work on it tomorrow =)

skimans, 2023-09-08:
> > @rtlopez now you must work for add GPS :) thanks much!!
>
> I am sure if you donate to him he will work on it tomorrow =)

do you have already donate....right ?

bsvdoom, 2023-09-08:
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

yes, code 🥇

skimans, 2023-09-08:
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

OK. Allora fatti i cazzi tuoi.
(use Goggle Translate for this..)

Closed 2023-09-09.

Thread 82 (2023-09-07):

Error to flash firmware

skimans, 2023-09-07:
hi
after using Arduino for check I2c address i have tried to reinstall firmware Alpha5, but when i flash i have this error message:

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

how i can solve it ?

rtlopez, 2023-09-07:
Hi @skimans

1. this screenshot is too small, it would be good if you provide fragment with upload configuration
2. what have you done so far to resolve this issue?
3. have you tried change cable or reset flash
4. have you read first google link https://www.google.com/search?q=md5+of+file+does+not+match+data+in+flash
5. do you have anything connected to gpio strapping pins 2 or 12?

skimans, 2023-09-07:
Hi @rtlopez  thanks for your patience.
I have read in the web also your link but i dont have found solution.
I have also changed the cable.
I think that i have bricked my ESP32 using Arduino.

Muchas gracias rtlopez. Creo que termina aca mi esperencia con ESP32.
Desculpame si te o molestado mucho a preguntarte muchas informaciones.
Sigue adelante asi con tu proyecto!
Felicidades!

rtlopez, 2023-09-07:
Hi @skimans No te rindas amigo y sigue adelante. Creo que lo lograrás :) Créeme, aprender también requiere paciencia :)

AutoPlantBali, 2023-09-08:
hi.. @skimans , follow this step:

=> connect esp32 and set bautrate 115200
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

=> set flash address and click program
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

=> finish
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

==> all file flash
[espfc.zip](https://github.com/rtlopez/esp-fc/files/12558669/espfc.zip)

skimans, 2023-09-08:
@AutoPlantBali thanks much! i have solved.
ESP32 recovered.

AutoPlantBali, 2023-09-08:
@skimans.... u're welcome... please close all issues that have been solved so that it's easier to handle

Closed 2023-09-09.

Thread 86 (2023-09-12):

v0.2.0-RC1 / SBUS is not working (only PPM works) / ESP32 (non mini)

ghehssalto, 2023-09-12:
Hello folks,

first of all that is an outstanding project thanks!

Currently I'm not able to use SBUS, however PPM is working, but I want to use SBUS :(.

My setup:
*Flysky FS-i6x+FSIA10B
*ESP32 (non mini)

rtlopez, 2023-09-12:
Hi @ghehssalto , can you show me the ports and receiver tabs? Which pin are you using to connect receiver? It must not be the same as ppm. You have to use serial rx pin of selected port. You can check pin assignments using cli command 'get pin'.

ghehssalto, 2023-09-12:
Hello now it's working THX!

But I have e new issue:

Every now and then it hangs completely and I have to reconnect and
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

then this message comes up
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

rtlopez, 2023-09-12:
@ghehssalto on which port did you set the serial rx option? is this problem on reveiver tab only or all? are you able to connect to CLI? if yes, type `reboot` and paste result here.

rtlopez, 2023-09-12:
@ghehssalto I forgot to mention, there are some quirks in connection to BF configurator. Usually it is impossible to connect right after flashing board. Powe cycle is required. Also if you enter CLI mode, you have to connect disconnect twice to leave. This issues shoud be eventually resolved in configurator, but it is not part of this project. Also similar issues might appear in connection of specific USB/UART chips or theirs drivers, especially when saving configuration that forces reboot.

In general I recommend:
1. disable auto-connect option in top of application window
2. disable autocomplete in configurator options

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

ghehssalto, 2023-09-13:
will try thx for your great support!

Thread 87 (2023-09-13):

Problem with Supported devices via SPI / Board ESP32 (non mini)

ghehssalto, 2023-09-13:
Hello,

currently the sensor MPU-92.65 is working in betaflight and the sensor MPU-9250/6500 is not working (Flag: NO_GYRO)

The interesting part is, if I plug in the sensor MPU-92.65 open betaflight and connect  & then unplug the sensor and plug in the
sensor MPU-9250/6500 gyro is working. I think there is a problem during initialization. But I'm not sure how to fix.

MPU-92.65 is working
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

MPU-9250/6500 is not working (Flag: NO_GYRO)
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

rtlopez, 2023-09-13:
Hi @ghehssalto, write here your connections between gyro and esp board.

ghehssalto, 2023-09-13:
yes sure:
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

ADO to pin 19
SCL to pin 18
SDA to pin 23
NCS to pin 5

rtlopez, 2023-09-13:
@ghehssalto It seems that your gyro module is based on MPU-6555. I've never meet such chip so far. I have to chek if it is comatible with MPU-6500 or MPU9250. In few days I can prepare special firmware to verify, but At the moment assume, it is not supported.

ghehssalto, 2023-09-13:
> @ghehssalto It seems that your gyro module is based on MPU-6555. I've never meet such chip so far. I have to chek if it is comatible with MPU-6500 or MPU9250. In few days I can prepare special firmware to verify, but At the moment assume, it is not supported.

Thank you very much for your research. How did you figure that out that it is based on the MPU-6555. Do you have a Link to taht page?

I bought that one MPU-9250/6500:
https://de.aliexpress.com/item/4001201664263.html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
(Note Pic is not matching the pic from above to the MPU-9250/6500 sensor.

rtlopez, 2023-09-13:
@ghehssalto I googled symbols on a chip. It is probably compatible, but retuns diferrent id so that it is not detected. With chinese counterfeit you never know what you get. I need to verify datasheet first.

skimans, 2023-09-13:
hi @ghehssalto this is MPU6500.
Many modules from Cina of this are MPU6500.
Few or none are MPU9250.

ghehssalto, 2023-09-13:
> @ghehssalto I googled symbols on a chip. It is probably compatible, but retuns diferrent id so that it is not detected. With chinese counterfeit you never know what you get. I need to verify datasheet first.

okay, are you looking @ the datasheet for mpu 6555?

ghehssalto, 2023-09-13:
> hi @ghehssalto this is MPU6500. Many modules from Cina of this are MPU6500. Few or none are MPU9250.

how do you know that or do u just assume? And If so why I have to do a workaround (see my first message above) to get them work? Because of de decide id?

AutoPlantBali, 2023-09-13:
hi @ghehssalto ...
I just added the mpu6555 ID to this firmware, you can try flashing it with this firmware
[firmware.zip](https://github.com/rtlopez/esp-fc/files/12601651/firmware.zip)

ghehssalto, 2023-09-13:
@AutoPlantBali
Thank you, but the connection is not made properly. It keeps like that:
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

AutoPlantBali, 2023-09-13:
@ghehssalto  Is there a serial monitor running in another application besides betaflight configurator?

ghehssalto, 2023-09-13:
@AutoPlantBali no, did you modify the most recent firmware version? Or an older one?

AutoPlantBali, 2023-09-13:
@ghehssalto I used v0.2.0-alpha5 and modified it, adding ID mpu6555 (0x7C) to the 6500 library. The chip can be read but can't use the library on the 6500 so it crashes when connected in betaflight

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

ghehssalto, 2023-09-14:
Could we try the same approach using v0.2.0-RC1?

AutoPlantBali, 2023-09-14:
@ghehssalto  I have made it with base v0.2.0-RC1.. flash with this firmware, if you still can't connect to the betaflight configurator, try opening the serial monitor (115200) and press the reset button, copy the log that appears.

[firmware.zip](https://github.com/rtlopez/esp-fc/files/12606929/firmware.zip)

ghehssalto, 2023-09-14:
@AutoPlantBali still not connecting to betaflight:

Serial monitor output:
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

AutoPlantBali, 2023-09-14:
@ghehssalto problem flash firmware, esp32 boot loop
same isssue
https://github.com/rtlopez/esp-fc/issues/82#issuecomment-1711475791

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
[fix-imu.zip](https://github.com/rtlopez/esp-fc/files/12607827/fix-imu.zip)

AutoPlantBali, 2023-09-14:
using all file in fix-imu.zip

skimans, 2023-09-14:
0x00 when flash firmware

ghehssalto, 2023-09-14:
> @AutoPlantBali still not connecting to betaflight:
>
> Serial monitor output: 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

Thank you, now it is connecting to betaflight but still no gyro is showing up. Same behavior as before.
"if I plug in the sensor MPU-92.65 open betaflight and connect & then unplug the sensor an plug in the
sensor MPU-9250/6500 gyro is workings."

ghehssalto, 2023-09-14:
> using all file in fix-imu.zip

Thank you, now it is connecting to betaflight but still no gyro is showing up. Same behavior as before.
"if I plug in the sensor MPU-92.65 open betaflight and connect & then unplug the sensor an plug in the
sensor MPU-9250/6500 gyro is workings."

AutoPlantBali, 2023-09-14:
Go to CLI, type reboot then enter... copy all the logs that appear here

ghehssalto, 2023-09-14:
Getting that log:

//# reboot
ets Jul 29 2019 12:21:46

rst:0xc (SW_CPU_RESET),boot:0x13 (SPI_FAST_FLASH_BOOT)
configsip: 0, SPIWP:0xee
clk_drv:0x00,q_drv:0x00,d_drv:0x00,cs0_drv:0x00,hd_drv:0x00,wp_drv:0x00
mode:DIO, clock div:1
load:0x3fff0030,len:1344
load:0x40078000,len:13864
load:0x40080400,len:3608
entry 0x400805f0
 I UART 0 0 1 115200 1 3

 I UART 1 1 1 115200 33 32

 I UART 2 2 64 100000 17 16

 I F_CPU 240000000

 E EEPROM wrong magic

 I SPI SETUP 18 23 19 1

 I I2C SETUP 21 22 1000 1

 I SPI DETECT MPU9250 5 0

 I SPI DETECT MPU6500 5 0

 IMU MPU6555
 I SPI DETECT MPU6555 5 0

 I SPI DETECT ICM20602 5 0

 I SPI DETECT LSM6DSO 5 0

 I I2C DETECT MPU9250 0

 I I2C DETECT MPU6500 0

 I I2C DETECT ICM20602 0

 I I2C DETECT MPU6050 0

 IMU MPU6555
 I I2C DETECT MPU6555 0

 I I2C DETECT LSM6DSO 0

 I MOTOR CONF 9 0 480 0

 I MOTOR PIN 0 27

 I MOTOR PIN 1 25

 I MOTOR PIN 2 4

 I MOTOR PIN 3 12

 I MOTOR PIN 4 -1

 I MOTOR PIN 5 -1

 I MOTOR PIN 6 -1

 I MOTOR PIN 7 -1

 I FUSION MAHONY 50

 I RX SBUS

AutoPlantBali, 2023-09-14:
I SPI DETECT MPU6555 5 0
I I2C DETECT MPU6555 0

not detected in spi and i2c for mpu6555, has this sensor ever been used and is working normally? Or is this the first time you use it when you buy it?

ghehssalto, 2023-09-14:
Yes it is the first time, I use it. If I read the register 117 (who_am_i) i receive the following integer values respectively.

sensor MPU-92.65 -> 112 (as it should be)

sensor MPU-9250/6500 -> 117

Maybe it's helpful.

AutoPlantBali, 2023-09-14:
@ghehssalto MPU-92.65 response 112 this is MPU6500
MPU-9250/6500 response 117 this is Unknown or fake Invensense IMU, use 'IMU_Generic'

reference:
https://github.com/AutoPlantBali/FastIMU/blob/17ade12e96c771c1a5fccb142871a039a173061f/examples/IMUIdentifier/IMUIdentifier.ino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

AutoPlantBali, 2023-09-14:
@ghehssalto do you want to try again, I made a response ID set to 117..

--> set flash address 0x10000
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

-->use this file:
[firmware.zip](https://github.com/rtlopez/esp-fc/files/12613970/firmware.zip)

Go to CLI, type reboot then enter... copy all the logs that appear here
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
ghehssalto, 2023-09-15:
@AutoPlantBali yes also according to the seller description.

But what is with the MPU-92.65, that one should work but it's not :(

skimans, 2023-09-15:
GY-91 module have compass inside MPU9250

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

but is not good use this compass beocuse there are many noises in the fly.

ghehssalto, 2023-09-15:
@skimans thank you for the information. So you are alway switching off the magnetometer?

But the point is I bought the MPU-92.65 as a 9-axis gyro so I want to use alle features. If not possible I have to contact the supplier :(.

skimans, 2023-09-15:
@ghehssalto usually i use magnetometer of module GPS..for example Beitian 880.
Mag is important to use only with GPS for Return to Home of quad using Gps_Rescue function in Betaflight.
For now is not important and you can disactivate.

ghehssalto, 2023-09-15:
@skimans Thanks know I got to Idea.

But anway I want check that the magnetometer of MPU-92.65 is working

ghehssalto, 2023-09-15:
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

Hello, I just checked today again and Heading is still increasing by +1 every 10 sec. using [base on mpu9250.zip](https://github.com/rtlopez/esp-fc/files/12614285/base.on.mpu9250.zip)

AutoPlantBali, 2023-09-15:
@ghehssalto disconnect and reconnect betaflight configurator...

ghehssalto, 2023-09-16:
@AutoPlantBali yes Heading keeps increasing by 1 deg/4 sec.

rtlopez, 2023-09-16:
@ghehssalto did you wait, until gyro calibration is finished? During this time gyro should not move. When finished you should see line "gyro bias ..." in terminal. Normaly it takes 2 seconds after powering board, but if gyro is poor or moving, it may never finish. Drift is symptom of lack callibration.

ghehssalto, 2023-09-16:
@rtlopez Thank you for your suggest. Yes I did it like that all the time, Heading is still increasing.

ghehssalto, 2023-09-16:
Could it be possible that neither my "MPU-92.65" nor my "MPU-9250/6500" has a magnetometer (tried via I2C & SPI BUS @ betaflight, with enabled magnetometer).

and device id 0x00 is responding random values
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

Read Reg. 0x00:
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

while Reg. 0x75 is returning 0x70 like it should be
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

Read Reg. 0x75:
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

rtlopez, 2023-09-17:
@ghehssalto If it retuns 0x70 it is mpu6500, mpu9250 should return 0x71, so none of your boards have mag. In 9250 compas is connected through external i2c bus, so you cannot access it directly, but only in bypass mode. So by reading reg 0x00 you accesed gyro, not mag.

ghehssalto, 2023-09-17:
@rtlopez Okay thanks.

Mathew3000, 2023-10-05:
The chips seem to be rebranded / relabled MPU6555 (at least they seem to be the same functionally).

Mathew3000, 2023-10-05:
The Gyro is connected and seems to be working, though I did not yet test it in flight.

Mathew3000, 2023-10-05:
Sorry @AutoPlantBali already discovered that 👍🏻

Mathew3000, 2023-10-05:
I just continue this issue here, the gyto seems to work fine when connected to the PC, but as soon as I lift off, the quad starts spinning on the yaw axis quite fast

rtlopez, 2023-10-05:
Hi @Mathew3000 check these things first
1. ensure that model i setup tab moves exacly in the same way as your device
2. ensure that motors spin in direction presented in motor tab
3. ensure that motors are connected in specified order like in motors tab
4. verify setting "Motor direction is reversed" in motors tab

Mathew3000, 2023-10-05:
Hey, after calibration, the random drift got better. For your suggestions:
1. I did, the model does move as I would expect
3. They spin in correct order
and I guess it was 2. and 4. combined, when I started the motors did not spin as I expected so I set "Motor direction is reversed" BUT that did not reverse the motors. My mistake was that after that I changed the pins on the motor but forgot to unset the reverse setting. I will try to check that tomorrow morning.

rtlopez, 2023-10-05:
"Motor direction is reversed" desn't reverse the motors, it only tells firmware that motors are configured in that way, so can correctly command motors. Motors direction can only be set in esc configuration or rather by swapping motor wires (because there is no esc serial passthrough in this firmware).

Mathew3000, 2023-10-05:
I use Betaflight for 4 Years and have never needed it 🤦🏻‍♂️

skimans, 2023-10-06:
@Mathew3000 you can change direction of motors also in Bhleli Configurator of your Esc's.

Mathew3000, 2023-10-06:
So after resetting the `Motor direction is reversed` switch the copter flew. I managed to crash it after a barrel-roll, the controller seemed to have had a runaway and at the end of the roll it flipped away. I' will try the next attempts with my EFC32 when it arrives

caixiaohai0, 2023-10-18:
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

Yours should be a refurbished gyroscope module. The refurbished chip does not have a magnetometer. Their prices are also different.

Closed 2023-11-08.

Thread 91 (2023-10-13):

missing arduinofake.h library

khunglong207, 2023-10-13:
I cannot perform PIO test on your project. They are missing quite a few libraries in the Test folder, so can you fix it for me?
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

rtlopez, 2023-10-13:
Hi @khunglong207 unit test works only with native environment, and you need to have gcc insatelled in system. Try command `pio test -e native`

khunglong207, 2023-10-14:
Hi @rtlopez  I tried it but it didn't work, The screen appears as follows:
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
And then I tried testing but the system still reported missing arduinofake.h library. Can you send me the root directory containing this library because I am working on a project and developing the raspberry pi system to do image processing. So I really need your help.
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

rtlopez, 2023-10-14:
@khunglong207 You are still running test for `esp8266` environment. Select `native` in bottom bar.
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

khunglong207, 2023-10-15:
i am using esp8266 microcontroller, so i set 8266 environment.

khunglong207, 2023-10-15:
Can you make a video about setup, I'm quite a noob about this issue

Mathew3000, 2023-10-15:
I think the tests are meant to run with 'default' env, that does not affect your 'esp8266' code

khunglong207, 2023-10-15:
Het bro can u help ke connect from esp 8266 to beta fight

khunglong207, 2023-10-15:
@Mathew3000
I TRIED trying to connect to beatfight but the system indicator is as shown below. How can I connect to betafight even though the baud rate I have set is 115200?
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

Mathew3000, 2023-10-15:
I use an esp32, but betaflight connects automatically as soon as I plug the esp into my computer, the message you see there indicates that the Configurator could not talk to / find a Betaflight controller on the port you selected

khunglong207, 2023-10-16:
@rtlopez , @Mathew3000

i don't understand what is the problem here, i have an esp8266 circuit. I connected to the computer and then I imported the code into the device. Then when it comes to the test environment, the system reports missing libraries like arduinofake.h; fakeit.h; ….
Connecting to betafight software, the system indicates USB reception as ttyUSB0 but cannot connect as shown above. Help me

rtlopez, 2023-10-16:
Hi @khunglong207 could you elaborate what are you trying to achieve?

To use this project you only need to run `build` and `flash` pio targets. Unit tests are designed to be able to run on local machine only and in the CI/CD pipline. On esp8266 `ArduinoFake` library is in conflict with `Arduino`.

About connection issues, ensure that user you are logged in, is assigned to `dialout` group on Linux. Without that you will not be able to connect and flash device through `/dev/ttyUSB0`. This command might help `sudo usermod -a -G dialout $USER`, and then logout and login again.

khunglong207, 2023-10-16:
hello @rtlopez
I am trying to make a flight controller on a quadrotor with an esp 8266 that uses an MPU6050 sensor; GPS
So first I tested the gryscope system by connecting the esp8266 and MPU6050 as shown in picture
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
First I flash like the instructions you told me in github, I flash successfully as shown below (I used your latest version RC-02).
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
Then, I build code using by platformIO from VS code, next I Pio run.
I opened betafight but it didn't work, even though I selected the correct tty/USB0 and the baudrate was 115200. I tried the code "sudo usermod -a -G dialout $USER" but it didn't work. What should I do next steps?
https://github.com/rtlopez/esp-fc/assets/142283805/2690d5db-d174-4c68-bce1-49d08042d6df

rtlopez, 2023-10-16:
hi @khunglong207 go to the options, and disable "advanced cli autocomplete". Let me know if it help, so I'll add this information to the redame file.

rtlopez, 2023-10-16:
@khunglong207 Also after flashing power cycle board by removing USB cable from port. For unknown reason betaflight-configurator is not able to connect right after flashing.

khunglong207, 2023-10-16:
The topology has been followed but it still doesn't work, can you teamview it with me?

rtlopez, 2023-10-16:
@khunglong207 try to connect using vscode terminal. If there are no messages, type `reboot` then later type `status` and paste result here.

khunglong207, 2023-10-16:
@rtlopez

How to connect terminal vs code, I'm new so I don't really understand

khunglong207, 2023-10-16:
In the video, I connected using the platform in vs code so I'm pretty sure the code was run on esp8266 but even in betafight it still didn't work.

khunglong207, 2023-10-16:
@rtlopez
i REBOOT AND STATUS IT
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

rtlopez, 2023-10-17:
@khunglong207 first picture shows that firmware works fine, gyro is correctly detected. I have no idea why configurator won't connect, it must be somethin with your system. I need some answers
1. Do you use more than one esp module? on first photo I see there is chip CH340, whilst on the screenshot above i see that that there is CP2102. Are you connecting to correct device? post here result of `lsusb` command, when board is connected.
2. are you connected in vscode terminal? You **cannot** use both at the same time.
3. Can you post here screenshot of the options tab?
4. what distribution and kernel version are you using?
5. try diferrent version of configurator 10.7 and 10.9 should work too.

khunglong207, 2023-10-17:
somehow i managed to connect to cp2102 drive with betafight but i can't connect to ch340 version i think because the drive version is different.
If I'm connected to betafight, I want to test run my motor, how can I do that? I'm in the motor section, but I don't know how to start it up. Can you help me?

Mathew3000, 2023-10-17:
Have you ever worked with Betaflight?
At this stage it should be basically just Betaflight standard stuff.
 - REMOVE YOUR PROPELLERS
 - connect power to your ESC
 - Toggle the "testmode switch"
 - SLOWLY move each motor slider up and down

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

caixiaohai0, 2023-10-18:
You should set the Flash Address to 0x0000 instead of 0x00

Mathew3000, 2023-10-18:
That should not make a difference, as both Values are refering to the start of the memory, same as 0x01 is the same as 0x0001

caixiaohai0, 2023-10-18:
> That should not make a difference, as both Values are refering to the start of the memory, same as 0x01 is the same as 0x0001

No, I also encountered this problem, this is my solution

Mathew3000, 2023-10-18:
I'm not doubting you, but that seems strange to me :D but I will remember :D

caixiaohai0, 2023-10-18:
> I'm not doubting you, but that seems strange to me :D but I will remember :D

Hahhh, it's not that you doubt it, but that I happen to have encountered this problem as well

khunglong207, 2023-10-18:
Thanks for all
but brushless motor not run this videohttps://github.com/rtlopez/esp-fc/assets/142283805/89dbacc8-b38f-42ae-bc98-e7069b94d40e

Mathew3000, 2023-10-18:
Did you select a motor protocol? and use the correct pins? because the beeping on your motor means the esc has not been initialised. This seems to be a PWM esc?

khunglong207, 2023-10-18:
yes this is brushless motor kv2212
esc XT60 ESC 40A
i connected correct Pin

Mathew3000, 2023-10-18:
Did you select the correct motor protocol? Because as long as the ESC is not initialised nothing will happen.

khunglong207, 2023-10-18:
i don't have a controller so i don't know the motor's protocol
can u help me

Mathew3000, 2023-10-18:
I mean, I can but don't you think it would be better to get a general understanding of what you are doing? I'm not sure if you should just use a FC project without knowledge of your stuff and just YOLO it... that seems dangerous.
If I need to guess I'd say you need to use PWM.
Also I would suggest you close this Issue, as this has nothing to do with the arduinofake library.

Closed 2023-10-18.

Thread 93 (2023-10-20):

Error MD5 of file does not match data in flash

ArshaanTech, 2023-10-20:
Hii! i am using a normal ESP32 board and there's continuous error. i have tried 4-5 times. i am using the latest firmware from releases.
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

ArshaanTech, 2023-10-20:
Sorry... My bad I just forgot to unzip it. works now! Thanks for this!

Closed 2023-10-20.

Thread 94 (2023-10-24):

ESC not working.

ArshaanTech, 2023-10-24:
Hi I am using "30A Brushless Motor Speed Controller RC Bec Esc for Quadcopter Plane Helicopter" ESC
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
and for some reason the motors are not spinning... I tried all the available protocols but no luck :( What could be the reason for this problem and how do I solve it.

khunglong207, 2023-11-08:
@rtlopez help pls

Mathew3000, 2023-11-08:
did you do a PWM calibration for your ESC? and can you confirm the signal is on the pin?

ArshaanTech, 2023-11-08:
just set the pwm frequency to 60 hertz and common the ground it will work!

Closed 2023-11-08.

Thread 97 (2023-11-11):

wobbly

ArshaanTech, 2023-11-11:
Hey! The flight controller is working! but there is a problem the drone keeps wobbling a lot which I think it shouldn't... anything I can do to help it?

Mathew3000, 2023-11-11:
Check the mounting of the IMU, this seems like a vibration issue to me. Otherwise check your pid tune

ArshaanTech, 2023-11-11:
The imu is mounted nicely with flex quick. pid is by default.

Mathew3000, 2023-11-11:
Depending on your quad you might need to tune the pid

ArshaanTech, 2023-11-11:
I don't actually know how to edit PID values... any suggestions?

ArshaanTech, 2023-11-11:
do you think i should rather use Double sided tape? or fevi quick is better

rtlopez, 2023-11-11:
@ArshaanTech We need more details about your build and configuration
1. list all used components and show photo of your build
2. go to the CLI tab and type `status` command and then `dump` and place result here
3. If you are using ESC that you asked in #94 then it is probably the reason, 60Hz is way below recommended rate, you need ESC, that supports OneShot125 protocol at least, and can be updated with 1000Hz.

ArshaanTech, 2023-11-11:
I changed the ESC im using a 4in BLHeli ESC with Dshot 600 firmware.
Im using ESP32 non mini, MPU6050 and a ppm receiver.
The frame is 3D printed custom.

Status:
```# status
ESPF ESP32 v0.2.0-RC2 e4ec8b3 Oct 11 2023 20:48:31 8.4.0 201103
STATUS:
    cpu freq: 240 MHz
  gyro clock: 8000 Hz
   gyro rate: 2000 Hz
   loop rate: 2000 Hz
  mixer rate: 2000 Hz
  accel rate: 501 Hz
   baro rate: 0 Hz
    mag rate: 0 Hz

 gyro device: MPU6050/I2C
 baro device: NONE
  mag device: NONE
     rx rate: 43
     rx lpfs: 0.00, 0.14

 arming disabled: 65542
```
dump:
```
dump
#ESPF ESP32 v0.2.0-RC2 e4ec8b3 Oct 11 2023 20:48:31 8.4.0 201103
set features 536870913
set debug_mode NONE
set debug_axis 1
set gyro_bus AUTO
set gyro_dev AUTO
set gyro_dlpf 256Hz
set gyro_align DEFAULT
set gyro_lpf_type PT2
set gyro_lpf_freq 100
set gyro_lpf2_type PT1
set gyro_lpf2_freq 213
set gyro_lpf3_type PT1
set gyro_lpf3_freq 150
set gyro_notch1_freq 0
set gyro_notch1_cutoff 0
set gyro_notch2_freq 0
set gyro_notch2_cutoff 0
set gyro_dyn_lpf_min 170
set gyro_dyn_lpf_max 425
set gyro_dyn_notch_q 300
set gyro_dyn_notch_count 4
set gyro_dyn_notch_min 80
set gyro_dyn_notch_max 400
set gyro_offset_x -156
set gyro_offset_y -97
set gyro_offset_z -19
set accel_bus AUTO
set accel_dev AUTO
set accel_lpf_type BIQUAD
set accel_lpf_freq 15
set accel_offset_x 292
set accel_offset_y -245
set accel_offset_z -134
set mag_bus AUTO
set mag_dev AUTO
set mag_align DEFAULT
set mag_filter_type BIQUAD
set mag_filter_lpf 10
set mag_offset_x 0
set mag_offset_y 0
set mag_offset_z 0
set mag_scale_x 1000
set mag_scale_y 1000
set mag_scale_z 1000
set baro_bus AUTO
set baro_dev AUTO
set baro_lpf_type BIQUAD
set baro_lpf_freq 10
set vbat_source NONE
set vbat_scale 100
set vbat_mul 1
set vbat_div 10
set vbat_cell_warn 350
set ibat_source NONE
set ibat_scale 100
set ibat_offset 0
set fusion_mode MAHONY
set fusion_gain_p 50
set fusion_gain_i 5
set input_rate_type ACTUAL
set input_roll_rate 20
set input_roll_srate 40
set input_roll_expo 0
set input_roll_limit 1998
set input_pitch_rate 20
set input_pitch_srate 40
set input_pitch_expo 0
set input_pitch_limit 1998
set input_yaw_rate 30
set input_yaw_srate 36
set input_yaw_expo 0
set input_yaw_limit 1998
set input_deadband 3
set input_min 885
set input_mid 1500
set input_max 2115
set input_interpolation AUTO
set input_interpolation_interval 26
set input_filter_type FILTER
set input_lpf_type PT3
set input_lpf_freq 0
set input_ff_lpf_type PT3
set input_ff_lpf_freq 0
set input_lpf_factor 50
set input_rssi_channel 0
set input_0 0 1000 1500 2000 A 1500
set input_1 1 1000 1500 2000 A 1500
set input_2 3 1000 1500 2000 A 1500
set input_3 2 1000 1500 2000 A 1000
set input_4 4 1000 1500 2000 H 1500
set input_5 5 1000 1500 2000 H 1500
set input_6 6 1000 1500 2000 H 1500
set input_7 7 1000 1500 2000 H 1500
set input_8 8 1000 1500 2000 H 1500
set input_9 9 1000 1500 2000 H 1500
set input_10 10 1000 1500 2000 H 1500
set input_11 11 1000 1500 2000 H 1500
set input_12 12 1000 1500 2000 H 1500
set input_13 13 1000 1500 2000 H 1500
set input_14 14 1000 1500 2000 H 1500
set input_15 15 1000 1500 2000 H 1500
set failsafe_delay 4
set failsafe_kill_switch 0
set serial_0 1 115200 115200
set serial_1 0 115200 115200
set serial_2 0 115200 115200
set serial_soft_0 1 115200 0
set scaler_0 0 0 20 400
set scaler_1 0 0 20 400
set scaler_2 0 0 20 200
set mode_0 0 4 1700 2100 0 0
set mode_1 1 5 900 1300 0 0
set mode_2 0 4 900 900 0 0
set mode_3 0 4 900 900 0 0
set mode_4 0 4 900 900 0 0
set mode_5 0 4 900 900 0 0
set mode_6 0 4 900 900 0 0
set mode_7 0 4 900 900 0 0
set pid_sync 1
set pid_roll_p 42
set pid_roll_i 85
set pid_roll_d 24
set pid_roll_f 72
set pid_pitch_p 46
set pid_pitch_i 90
set pid_pitch_d 26
set pid_pitch_f 76
set pid_yaw_p 45
set pid_yaw_i 90
set pid_yaw_d 0
set pid_yaw_f 72
set pid_level_p 55
set pid_level_i 0
set pid_level_d 0
set pid_level_angle_limit 55
set pid_level_rate_limit 300
set pid_level_lpf_type PT1
set pid_level_lpf_freq 90
set pid_yaw_lpf_type PT1
set pid_yaw_lpf_freq 90
set pid_dterm_lpf_type PT1
set pid_dterm_lpf_freq 128
set pid_dterm_lpf2_type PT1
set pid_dterm_lpf2_freq 128
set pid_dterm_notch_freq 0
set pid_dterm_notch_cutoff 0
set pid_dterm_dyn_lpf_min 60
set pid_dterm_dyn_lpf_max 145
set pid_dterm_weight 30
set pid_iterm_limit 30
set pid_iterm_zero 1
set pid_iterm_relax RP
set pid_iterm_relax_cutoff 15
set pid_tpa_scale 10
set pid_tpa_breakpoint 1650
set mixer_sync 1
set mixer_type QUADX
set mixer_yaw_reverse 1
set mixer_throttle_limit_type NONE
set mixer_throttle_limit_percent 100
set mixer_output_limit 100
set output_motor_protocol DSHOT150
set output_motor_async 0
set output_motor_rate 480
set output_servo_rate 0
set output_min_command 1000
set output_min_throttle 1070
set output_max_throttle 2000
set output_dshot_idle 550
set output_0 M N 1000 1500 2000
set output_1 M N 1000 1500 2000
set output_2 M N 1000 1500 2000
set output_3 M N 1000 1500 2000
set output_4 M N 1000 1500 2000
set output_5 M N 1000 1500 2000
set output_6 M N 1000 1500 2000
set output_7 M N 1000 1500 2000
set pin_input_rx 35
set pin_output_0 14
set pin_output_1 25
set pin_output_2 27
set pin_output_3 26
set pin_output_4 -1
set pin_output_5 -1
set pin_output_6 -1
set pin_output_7 -1
set pin_buzzer 0
set pin_serial_0_tx 1
set pin_serial_0_rx 3
set pin_serial_1_tx 33
set pin_serial_1_rx 32
set pin_serial_2_tx 17
set pin_serial_2_rx 16
set pin_i2c_scl 22
set pin_i2c_sda 21
set pin_input_adc_0 36
set pin_input_adc_1 39
set pin_spi_0_sck 18
set pin_spi_0_mosi 23
set pin_spi_0_miso 19
set pin_spi_cs_0 5
set pin_spi_cs_1 13
set pin_spi_cs_2 -1
set pin_buzzer_invert 1
set i2c_speed 1000
set telemetry_interval 1000
set blackbox_dev 0
set blackbox_mode NORMAL
set blackbox_rate 32
set blackbox_mask 0
set wifi_mode OFF
set wifi_ssid
set wifi_pass
set wifi_ssid_ap
set wifi_pass_ap
set wifi_tcp_port 1111
set mix_outputs -4
set mix_0 0 0 0
set mix_1 0 0 0
set mix_2 0 0 0
set mix_3 0 0 0
set mix_4 0 0 0
set mix_5 0 0 0
set mix_6 0 0 0
set mix_7 0 0 0
set mix_8 0 0 0
set mix_9 0 0 0
set mix_10 0 0 0
set mix_11 0 0 0
set mix_12 0 0 0
set mix_13 0 0 0
set mix_14 0 0 0
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
ArshaanTech, 2023-11-12:
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

Here is the image of the drone
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

And also the video:

<!-- Error while uploading VID_20231112_161954.mp4 -->

rtlopez, 2023-11-12:
@ArshaanTech for me it is slow woble/oscillation, I'm pretty sure, it is because of low pid gains and lack of air mode. So you can try
1. enable air mode in modes tab
2. In pid tuning tab move master gain slider to the right, by one step and try again

If you notice that it is better, but not enough, move slider next step. Repeat by one step until you feel locked in. If you notice, fast oscilations like shaking, and motor sound modulation, then step back, you hit the limit.

I don't think, that old esp32 module is the reason.

ArshaanTech, 2023-11-13:
Okay, I will change the frame and use a sturdy frame from the market.
I will enable air mode and I will also try the PID slider.

ArshaanTech, 2023-11-15:
The same issue persists, The drone is still oscillating and is also drifting. I calibrated the accelerometer and gyro and the receiver values to 1500 uS.
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
I ensured there are no moving parts in the drone. everything was stuck well with double-sided tape. Airmode was turned on and I increased PID values.
Nothing works so far.

https://github.com/rtlopez/esp-fc/assets/85013497/960be549-0ae5-4d93-b375-c3ef89ff3ea6

can there be any other cause for the issue?

Mathew3000, 2023-11-15:
This seems to be still an issue with your tune. Id say. That said, I have tried but never succeeded in flying the F450 frame with Betaflight(stm32)

Mathew3000, 2023-11-15:
Your propellers seem quite small to me compared to your framesize. But that might also just be from the images

ArshaanTech, 2023-11-15:
oh... okay so I guess this is just not the right flight controller for this quad?
The propellers are not the issue bcz they fit right.
is it possible to share a footage of the drone you have built, like how stable it is during angle or acro? possible to show?

rtlopez, 2023-11-15:
@ArshaanTech My 5''/4S quad is rock solid https://www.youtube.com/watch?v=22mlmE2FoF0
I have no experience with building such big quads, there is so many factors and without blackbox we can only guess, whats going on. I recommend to investing in this small device. Recently I've created setup instruction https://github.com/rtlopez/esp-fc/blob/master/docs/setup.md and there is mentioned how to connect sd logger.

The second video you've attached is exactly the same as first, was it intentional?

What exactly motors, propellers and batery are you using, maybe your quad is underpowered. Paste your new settings here.

ArshaanTech, 2023-11-15:
Okay i will use 10" props. and I'm sorry for the wrong attachment.

https://github.com/rtlopez/esp-fc/assets/85013497/49ab395d-bc95-437f-82a4-0ea3c1e187dc

The new settings are

1. 3s battery 60c 2200mAh
2. 2212 1000kV motors
3. BLHeli 30A 4 in 1 ESC (Dshot600)
4. 6" props - I'll use 10" from next time
5. F450 frame

ArshaanTech, 2023-11-16:
i will try with 1045, also is it better to use mpu6500 and 8khz instead of mpu6050, is there any noticeable difference?

rtlopez, 2023-11-16:
For experienced and demanding users, this may be noticeable. It provides better filtering, less delay, allows the use of higher pid gains and gives a better lock-in effect. But this also requires higher quality components and PID tuning skills. Personally, I recommend using the SPI interface if possible as I2C is about 10 times slower.

ArshaanTech, 2023-11-16:
Okay bro Thanks for the advice! I'll take it into consideration. Btw do you have any plans for working on VTX on screen display?
I think it would be pretty nice to read analog battery voltage and display it on the FPV feed.

rtlopez, 2023-11-16:
Look for a Minim OSD device, it should work, via UART/MSP As far as I know.

ArshaanTech, 2023-11-19:
still the same problem. I'll just build a new quad when i have enough money.

ArshaanTech, 2023-11-19:
Do you intend on making newer firmware and solving the current betaflight problems? many things that I turn on just turn off automatically after a reboot, The qmc5883 sensor also not working. it's also better to add VTX support. I would say adding GPS and return to launch would be nice. i can help you with the testing if you want. Any plans?

rtlopez, 2023-11-20:
If you could choose only one function, what would it be?

ArshaanTech, 2023-11-22:
> If you could choose only one function, what would it be?

I would like it to be GPS. I think it's nice to have a return to launch at failsafe instead of the drone dropping from mid air. Atleast landing functionality should be enabled. Can you contact me on discord? I would love to help you out in any way I can, Although I'm not an expert at betaflight firmwares.

Closed 2023-12-12.

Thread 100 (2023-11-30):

Inbuilt wifi/Bluetooth can be used as receiver??

PravarHegde, 2023-11-30:
I would like to use built-in wifi as transmitter and receiver instead of external transceiver. It would be light weight so can be used for Brushed nano drone.

AutoPlantBali, 2023-12-01:
@PravarHegde The internal WiFi configuration has been used for BetaFlight Configurator connections via TCP/IP, you can check it in the CLI

AutoPlantBali, 2023-12-01:
rx elrs ep1, ep2, pp only weighs 0.44 - 0.5 gr, is this still heavy enough?

PravarHegde, 2023-12-01:
Yes correct.  But it's not cost effective. Esp8266 flight controller would be around 300₹ (3.6$) . Happymodel 2.4GHz ELRS nano series receiver cost around 1500₹ ( 18 $) and nrf24 module cost around 80₹ (1$ ) .  elrs model cost around  5 times of flight controller.  That's why . Using Nrf24 connection or built-in wifi as receiver would be cost effective 🤔

AutoPlantBali, 2023-12-02:
@PravarHegde The weight of the receiver is inversely proportional to the price, if you want it cheap maybe you can make it yourself from Github:
https://github.com/RomanLut/hx_espnow_rc

rtlopez, 2023-12-02:
Hi @PravarHegde, I was thinking about it too and so far I haven't found a radio system that would be able to work directly with the ESP32. Do you have any suggestion?

rtlopez, 2023-12-03:
@PravarHegde Note that it is not betaflight, this is completely differrent firmware, only betaflight configurator can be used to configure it. I think it's time to start thinking about forking the configurator, because many people often think it's betaflight.

I don't think a smartphone will give any good user experience. Especially Wifi consumes a lot of processing power, that would negatively affect overral performance. Also wifi connection suffer a lot in range and realiability. nfr24 would be an option, as the 4in1 multiprotocol module would be able to handle that. But that would significantly complicate the PCB and firmware. In my opinion, it is best to stick to proven and battle-tested solutions. But I don't mind if there is anyone willing to build and implement it ;)

AutoPlantBali, 2023-12-04:
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

The espcopter is a different firmware, the controller on the smartphone uses remoteXY apps, the flight distance is short and unstable for some smartphones.

Boak29, 2023-12-04:
> Okay but reciver weight would be heavy for Brushed tiny drones. So  it would be better if  we can use inbuilt wifi or it would be better if we can add nrf24 module as receiver (through spi)

You can use wifippm with esp12, if it still feels heavy use esp01

Closed 2023-12-12.

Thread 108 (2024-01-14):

support for esp32-s2 and esp32-s3

sysytwl, 2024-01-14:
I have an esp32-s3 board. tried. But it doesn't work. It may be a USB virtual serial port problem. Because I can feel the CPU temperature. Can anyone tell me where the serial port file is? Or how to modify it. I'm new to PlatformIO.

rtlopez, 2024-01-14:
s2,s3,c3 aren't released yet, but work is in progress. If you have enough development skills you can try to use this branch https://github.com/rtlopez/esp-fc/pull/106

Boak29, 2024-01-29:
Hi mr, I have tried it and it was successful with my lolin s2 mini, thank you, but there are i2c error 4 errors, how can I fix it?

rtlopez, 2024-01-29:
Hi, this is not an issue, small numer of error occurs because FC try to detect devices that are not present. Problem is if the numer of errors increases.

Boak29, 2024-01-29:
many Thanks mr

Closed 2024-01-14.

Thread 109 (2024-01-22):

Betaflight cant connect over WiFi

Bleach665, 2024-01-22:
First of all, many thanks to @rtlopez for a great project!

I try to connect Betaflight to esp32 over WiFi, but receive error `Failed to open serial port`.
In serial console all work perfect:
<details>

````
# status
ESPF ESP32 v0.0.0 0000000 Jan 22 2024 15:11:44 8.4.0 201103
STATUS:
    cpu freq: 240 MHz
  gyro clock: 8000 Hz
   gyro rate: 2000 Hz
   loop rate: 250 Hz
  mixer rate: 250 Hz
  accel rate: 500 Hz
   baro rate: 83 Hz
    mag rate: 75 Hz

 gyro device: MPU6050/I2C
 baro device: BMP280/I2C
  mag device: HMC5883L/I2C
     rx rate: 43
     rx lpfs: 0.00, 0.14

 arming disabled: 16777222

````
</details>

Also, Betaflight configurator work fine over COM port.

To connect over WiFi I set in COM port console SSID, password, `wifi_mode` to `1`. After `save` and `reboot`. On this step, esp32 present in router clients list. Also, I can ping it. In betaflight configurator I select `Manual selection` on `Welcome` page. In `port` I enter esp32 ip adress: `tcp://192.168.1.36`. And receive described above arror.
Betaflight configurator ver. 10.8 and 10.9 were tried.

rtlopez, 2024-01-23:
You need to specify port numer with address, by default it is 1111: `tcp://192.168.1.36:1111`

Closed 2024-01-23.

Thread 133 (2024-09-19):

flashing problem in esptool!

Zuhayer69, 2024-09-19:
I have a esp 32 dev module rev3 which i connected through usb and in esp tool i conected the board but I am am confused what file i should select for the firmware. Please tell me the firmware file name basically which file to choose to flash.

rtlopez, 2024-09-19:
espfc_v0.2.0-RC6_esp32_0x00.bin.zip, remeber to extract and follow guide https://github.com/rtlopez/esp-fc?tab=readme-ov-file#flashing

Zuhayer69, 2024-09-23:
> `espfc_v0.2.0-RC6_esp32_0x00.bin.zip`, remeber to extract and follow guide https://github.com/rtlopez/esp-fc?tab=readme-ov-file#flashing
Thanks for the reply I am going to test it as soon as possible and I will let you know

rtlopez, 2024-09-27:
esp32-c3 and esp32-s3 is not supported by this flasher. At the moment you need to use vscode with platformio extension.

Zuhayer69, 2024-09-27:
Will the schematics be same for the esp32 s3 module as the esp32 module? Or there is a difference ?

rtlopez, 2024-09-27:
no, pin assignment is diferrent. If you flash board, then go to the Cli and type `get pin` to see pin functions.

Zuhayer69, 2024-10-07:
the ADC pin for esp32 is two shown in the CLI one is ADC 0 and another is ADC 1 which one to use? please help

bsvdoom, 2024-10-07:
> the ADC pin for esp32 is two shown in the CLI one is ADC 0 and another is ADC 1 which one to use? please help

Try ADC 0

rtlopez, 2024-10-07:
ADC_0 is for voltage, ADC_1 is for current. Do not confuse it with internal `ADC` number of esp chip. Use only pins attached to `ADC1` of esp32.

Closed 2024-11-23.

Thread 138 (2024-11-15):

Custom Controller

KeithHanson, 2024-11-15:
Firstly, sir... Amazing work. I have both an esp32 and an esp32s3 wired up and registering in beta flight now 😍

https://bsky.app/profile/keithhanson.bsky.social/post/3layxvo6yos2l

I'd like to hook up a heltec Lora to this, but modify the code to support having the FC double as the remote control receiver.

Firstly - is this even a good idea? I have yet to dive into the code, but I'm hoping I can use the multiple cores - one for FC work, one to receive packets.

My hope is to create a simple app on my steamdeck so I can use it as a ground station (FPV feed) and control (a simple pygame prototype for now that communicates with another heltec Lora via usb serial).

Secondly, if this is not a BAD idea and could be implemented, would you mind highlighting the areas of code to modify?

I'm betting if I look around at how you've implemented the esp-now control, it'd be similar, but having your insight will save a lot of time :)

Many thanks for this project! Can't wait to get my first esp32 controller drone in the air!

bsvdoom, 2025-01-14:
As far as I know, LoRa is only for very small packets and listening in the 99.99% of the time.
It also has very big latency, so it is not suitable to remote control anything real-time.

rtlopez, 2025-02-04:
@KeithHanson I admit that it would be interesting to have a steam deck as a controller with its FPV screen, if I got it correctly. But I don't know its capabilities at all, so it's hard for me to judge whether it's possible. I'm also not able to point out places for modifications, because first you would have to do some analysis and make some design decisions. But I hope that won't stop you from implementing it. From what I can say now, both cores are alredy utilized.

@bsvdoom Do you know ExpressLRS project? it's LoRa on SX1280 chip essencially.

bsvdoom, 2025-02-06:
@rtlopez Ofc, I have a Radiomaster pocket, and I love it!
What I meant was that the SX1262 is designed specifically for LoRa (Chirp Spread Spectrum) and FSK (Frequency Shift Keying) modulation, and optimized for low data rates, and has a maximum data rate of around 27 kbps, which is far lower than what’s required for real-time drone control.
Also the round-trip latency is between 100 milliseconds and 500 milliseconds, or more.
The SX1262 is built for LoRa protocol and simple data transmission protocols (e.g., LoRaWAN), and it doesn’t support the necessary functionality for real-time control or frequency hopping.

Closed 2025-02-04.

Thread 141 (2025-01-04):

problem in connecting SBUS with esp32 s3 mini board (which pin to use!!??)

Zuhayer69, 2025-01-04:
I have a esp32 s3 mini board where i have flashed the firmware and now i want to connect the flysky receiver with SBUS protocol but which pin I should use I am confused and please tell what is the process to connect the receiver in beta flight. Here is the picture of the pins of the esp32 s3
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

rtlopez, 2025-01-04:
SBUS is serial protocol, that means you need to enable serial rx function in port tab on selected uart. Then select SBUS protocol in receiver tab. Once it is done you can connect receiver to pin mapped on `pin_serial_{0,1,2}_rx`.

Zuhayer69, 2025-01-05:
which one of the uart to use?
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

rtlopez, 2025-01-05:
use any free one convenient for you

Zuhayer69, 2025-01-07:
if i use uart 1 then i have to connect sbus pin to serial rx 0?

rtlopez, 2025-01-07:
yes

Zuhayer69, 2025-01-10:
i am facing problem with the battery. using a 3.7v battery i have connect 220k ohm and 1mega ohm resistor to make a voltage divider and connected it to the pin 1 but there is no voltage showing. do i have to do something in the power tab of beta flight?

rtlopez, 2025-01-10:
1. are you using 220k:1M or 1M:220k? Keep in mind, that fully charged battery has 4.2V. In this case I recommend 150k:220k divider (150k to battery, 220k to ground, or 15k:22k)
2. you must connect divider to pin assigned to `pin_input_adc_0` in cli
3. in power tab select "Onboard ADC" and tune scale to display real measurement (probably +/-10)

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

Zuhayer69, 2025-01-10:
i didnt knew the orientation mattered so im gonna fix that what about the calibration button?

Zuhayer69, 2025-01-10:
can you give me the equation of the divider and multiplier values

rtlopez, 2025-01-10:
if scale = 10, then for multiplier and divider you can use real resistor values. if scale = 100, then decrease multiplier 10 times or increase divider 10 times. Proposed values above should be good for start in your case. You can use calibration button.

Closed 2025-02-04.

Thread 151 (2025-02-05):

Problem with ESP-NOW Configuration → SPI Rx (e.g. built-in Rx)

copilador, 2025-02-05:
Hello, I am trying to set up a drone with ESP-NOW (espfc_v0.2.1) enabled. If I understand correctly, I need to configure the position of SPI Rx (e.g., built-in Rx) in the receiver tab. However, after selecting SPI Rx (e.g., built-in Rx), saving, and restarting, I can no longer access the ESP32.

When I check the serial console, I see that it keeps rebooting with the following message:
Brownout detector was triggered

ets Jul 29 2019 12:21:46

rst:0xc (SW_CPU_RESET),boot:0x13 (SPI_FAST_FLASH_BOOT)
configsip: 0, SPIWP:0xee
clk_drv:0x00,q_drv:0x00,d_drv:0x00,cs0_drv:0x00,hd_drv:0x00,wp_drv:0x00
mode:DIO, clock div:1
load:0x3fff0030,len:1344
load:0x40078000,len:13964
load:0x40080400,len:3600
entry 0x400805f0

I had to reprogram the ESP32, but when I tried again, it started rebooting continuously once more. I'm not sure what I'm doing wrong, or could the problem be due to using SPI to access the sensors? My configuration is:
set pin_input_rx 35    --->PPM ?? should be -1 ???
set pin_output_0 27    --->PWM -M1
set pin_output_1 25    --->PWM -M2
set pin_output_2 4     --->PWM -M3
set pin_output_3 26    --->PWM -M4
set pin_output_4 -1
set pin_output_5 -1
set pin_output_6 -1
set pin_output_7 -1
set pin_buzzer -1
set pin_serial_0_tx 1  --->TX0
set pin_serial_0_rx 3  --->RX0
set pin_serial_1_tx 33--->TX1
set pin_serial_1_rx 32--->RX1
set pin_serial_2_tx 17--->TX2
set pin_serial_2_rx 16--->RX2
set pin_i2c_scl 22    --->SCL  Unused
set pin_i2c_sda 21    --->SDA  Unused
set pin_input_adc_0 36--->ADC VOLTAGE
set pin_input_adc_1 -1
set pin_spi_0_sck 18  --->SPI0 CLK
set pin_spi_0_mosi 23 --->SPI0 MOSI
set pin_spi_0_miso 19 --->SPI0 MISO
set pin_spi_cs_0 5    --->CS MPU-9250
set pin_spi_cs_1 13   --->CS BMP280
set pin_spi_cs_2 -1
set pin_buzzer_invert 1

Thanks!

rtlopez, 2025-02-05:
Brownout means that your power supply or battery is not able to provide enough current so voltage drops below minimum.

copilador, 2025-02-06:
Thank you, you're right, it's a problem with the voltage regulator. When the radio part is activated, the consumption increases and the regulator I'm using, AP2112K-3.3, is not suitable. I'll have to find another solution...

bsvdoom, 2025-02-15:
> Thank you, you're right, it's a problem with the voltage regulator. When the radio part is activated, the consumption increases and the regulator I'm using, AP2112K-3.3, is not suitable. I'll have to find another solution...

@copilador
AP2112K-3.3 should handle 600mA, and ESP32 in active mode should only consume maximum 260mA.
However it can burst to 1A, so try adding a bigger cap before and after the AP2112.

Closed 2025-02-06.

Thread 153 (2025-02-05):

receiver isnt getting detected

colaco1123, 2025-02-05:
I have an radiomaster r81 receiver with supports frskyd8 and gives a subs output i connected this signal pin to pin 17 on the esp32s3 supposedly the pin_serial_2_rx 17 but i don't seem to be able to get the receiver connected i think its something with regards to sbus inversion or so
i tried it with uart 1 too on pin 15 no luck
can you please help me solve this issue thankyou

here is links to the receiver
https://quadkart.in/radiomaster-r81-8ch-frsky-d8-compatible-nano-receiver-w-sbus/

rtlopez, 2025-02-06:
1. did you bind receiver and transmitter?
2. attach screenshot of `ports` and `receiver` tabs

colaco1123, 2025-02-06:
yes the transmitter and receiver are connected and working fine

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

colaco1123, 2025-02-06:
yes i have used this receiver before i used the sbus.h library
and a definition like below (pin numbers are different)
bfs::SbusRx sbus_rx(&Serial2,11, 12,true);
bfs::SbusData data;

the wiring is just sbus to pin 17

colaco1123, 2025-02-06:
here check this under sbus it says "Some OpenLRS receivers produce a non-inverted SBUS signal. It is possible to switch SBUS inversion off using CLI command set sbus_inversion = OFF when using an F3 based flight controller."

but the esp_fc firmware doesnt have the set sbus_inversion parameter

https://betaflight.com/docs/development/rx

rtlopez, 2025-02-06:
if you choose UART3 then you must connect to pin assigned to `pin_serial_2_rx`, on esp32s3 by default is GPIO17 (in CLI they are 0indexed). On ESP32-S3-Zero this is an inner pad, so you might want to remap it to diferrent pin in CLI (see attachment) if you want to have it on outer pad, or use diferrent UART.

ExpressLRS has option to generate non-inverted SBUS, but it is not option in your case. Esp32 chip supports serial inversion and it is enabled fo SBUS, but firmware doesn't have any config to change it.

Does the code you attached works for you?

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

rtlopez, 2025-02-06:
do you have logic analyzer to capture signal trace?

colaco1123, 2025-02-06:
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

Yes the pin in connected to the inside pad infact before this i tried it with part 1 but it was the same

Yes the code i attached works in getting sbus data onto the serial monitor in  Arduino

colaco1123, 2025-02-06:
> do you have logic analyzer to capture signal trace?

Yes I have one at my workplace i shall try to send you the waveform.

rtlopez, 2025-02-06:
On this picture I see that digital signal is transferred, but it would be good to see whole frame timings (frame time and space time) and idle level. Ideally at least 2 frames on a screen. Technically it should by about 3ms data frame, 6ms idle space, and 0 at idle. like this:

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

I've tested firmware v0.2.1 with Frsky XM+, and it works correctly.

Did you chang any pin assignment? go to the cli, type following commands, and paste results here (rx must be connected, ensure that is is powered by 5V)
```
get pin
status
logs
```

colaco1123, 2025-02-07:
ESPF ESP32S3 v0.2.1 120a1a6 Feb  4 2025 21:46:59 1.43 8.4.0 201103
STATUS:
    cpu freq: 240 MHz
  gyro clock: 8000 Hz
   gyro rate: 2000 Hz
   loop rate: 2000 Hz
  mixer rate: 2000 Hz
  accel rate: 500 Hz
   baro rate: 54 Hz
    mag rate: 75 Hz

     devices: MPU6050/I2C, BMP085/I2C, QMC5883L/SLV
       input: 43 Hz, 0.00 Hz, 0.14
arming flags: FAILSAFE RX_FAILSAFE CLI MSP REBOOT_REQUIRED MOTOR_PROTOCOL
 rescue mode: 1
      uptime: 85.5

colaco1123, 2025-02-07:
well apparently after this i tried to flash it again and it works now thankyou so much for your help im an undergrad student and this is one of my few projects. i love your work thankyou so much for helping me.

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

Closed 2025-02-07.

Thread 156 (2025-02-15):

Issue when enabling motors in PWM mode?

copilador, 2025-02-15:
Hello, I’m having issues configuring motor control via PWM. I see that it is indicated as not recommended, but I believe it is supported? I’m using a nano drone with coreless DC motors (3.7V, 70,000 RPM) and ESP-NOW control mode. Everything seems to work correctly, except when I enable PWM mode with set output_motor_protocol PWM. After saving and restarting, the motors start running at high speed, and I can see a PWM signal on the GPIO outputs. Is PWM mode supported?
Thanks.

Entering CLI Mode, type 'exit' to return, or 'help'
 ESPF ESP32 v0.2.1 120a1a6 Feb  4 2025 21:46:48 1.43 8.4.0 201103
 dump
defaults
set features 33554432
set debug_mode NONE
set debug_axis 1
set gyro_bus AUTO
set gyro_dev AUTO
set gyro_dlpf 256Hz
set gyro_align DEFAULT
set gyro_lpf_type PT1
set gyro_lpf_freq 100
set gyro_lpf2_type PT1
set gyro_lpf2_freq 213
set gyro_lpf3_type FO
set gyro_lpf3_freq 150
set gyro_notch1_freq 0
set gyro_notch1_cutoff 0
set gyro_notch2_freq 0
set gyro_notch2_cutoff 0
set gyro_dyn_lpf_min 170
set gyro_dyn_lpf_max 425
set gyro_dyn_notch_q 814
set gyro_dyn_notch_count 4
set gyro_dyn_notch_min 2640
set gyro_dyn_notch_max -359
set gyro_rpm_harmonics 19
set gyro_rpm_q 500
set gyro_rpm_min_freq 118
set gyro_rpm_fade 30
set gyro_rpm_weight_1 100
set gyro_rpm_weight_2 100
set gyro_rpm_weight_3 100
set gyro_rpm_tlm_lpf_freq 150
set gyro_offset_x 4
set gyro_offset_y 2
set gyro_offset_z 11
set accel_bus AUTO
set accel_dev AUTO
set accel_lpf_type BIQUAD
set accel_lpf_freq 15
set accel_offset_x 7521
set accel_offset_y -11412
set accel_offset_z 9795
set mag_bus AUTO
set mag_dev NONE
set mag_align DEFAULT
set mag_filter_type BIQUAD
set mag_filter_lpf 10
set mag_offset_x 0
set mag_offset_y 0
set mag_offset_z 0
set mag_scale_x 1000
set mag_scale_y 1000
set mag_scale_z 1000
set baro_bus AUTO
set baro_dev NONE
set baro_lpf_type BIQUAD
set baro_lpf_freq 10
set board_align_roll 0
set board_align_pitch 0
set board_align_yaw 0
set vbat_source ADC
set vbat_scale 110
set vbat_mul 1
set vbat_div 3
set vbat_cell_warn 350
set ibat_source NONE
set ibat_scale 100
set ibat_offset 0
set fusion_mode MAHONY
set fusion_gain_p 50
set fusion_gain_i 5
set input_rate_type ACTUAL
set input_roll_rate 20
set input_roll_srate 40
set input_roll_expo 0
set input_roll_limit 1998
set input_pitch_rate 20
set input_pitch_srate 40
set input_pitch_expo 0
set input_pitch_limit 1998
set input_yaw_rate 30
set input_yaw_srate 36
set input_yaw_expo 0
set input_yaw_limit 1998
set input_deadband 3
set input_min 885
set input_mid 1500
set input_max 2115
set input_interpolation AUTO
set input_interpolation_interval 26
set input_filter_type FILTER
set input_lpf_type PT3
set input_lpf_freq 0
set input_lpf_factor 50
set input_ff_lpf_type PT3
set input_ff_lpf_freq 0
set input_rssi_channel 0
set input_0 0 1000 1500 2000 A 1500
set input_1 1 1000 1500 2000 A 1500
set input_2 3 1000 1500 2000 A 1500
set input_3 2 1000 1500 2000 A 1000
set input_4 4 1000 1500 2000 H 1500
set input_5 5 1000 1500 2000 H 1500
set input_6 6 1000 1500 2000 H 1500
set input_7 7 1000 1500 2000 H 1500
set input_8 8 1000 1500 2000 L 1500
set input_9 9 1000 1500 2000 H 1500
set input_10 10 1000 1500 2000 H 1500
set input_11 11 1000 1500 2000 H 1500
set input_12 12 1000 1500 2000 H 1500
set input_13 13 1000 1500 2000 H 1500
set input_14 14 1000 1500 2000 H 1500
set input_15 15 1000 1500 2000 H 1500
set failsafe_delay 4
set failsafe_kill_switch 0
set serial_0 1 115200 0
set serial_1 1 115200 0
set serial_2 64 115200 0
set serial_soft_0 1 115200 0
set scaler_0 0 0 20 4p0
set scaler_1 0 0 20 400
set scaler_2 0 0 20 200
set mode_0 0 5 1950 2100 0 0
set mode_1 0 4 900 900 0 0
set mode_2 0 4 900 900 0 0
set mode_3 0 4 900 900 0 0
set mode_4 0 4 900 900 0 0
set mode_5 0 4 900 900 0 0
set mode_6 0 4 900 900 0 0
set mode_7 0 4 900 900 0 0
set pid_sync 8
set pid_roll_p 42
set pid_roll_i 85
set pid_roll_d 24
set pid_roll_f 72
set pid_pitch_p 46
set pid_pitch_i 90
set pid_pitch_d 26
set pid_pitch_f 76
set pid_yaw_p 45
set pid_yaw_i 90
set pid_yaw_d 0
set pid_yaw_f 72
set pid_level_p 45
set pid_level_i 0
set pid_level_d 0
set pid_level_angle_limit 55
set pid_level_rate_limit 300
set pid_level_lpf_type PT1
set pid_level_lpf_freq 90
set pid_yaw_lpf_type PT1
set pid_yaw_lpf_freq 90
set pid_dterm_lpf_type PT1
set pid_dterm_lpf_freq 128
set pid_dterm_lpf2_type PT1
set pid_dterm_lpf2_freq 128
set pid_dterm_notch_freq 0
set pid_dterm_notch_cutoff 0
set pid_dterm_dyn_lpf_min 60
set pid_dterm_dyn_lpf_max 1169
set pid_dterm_weight 30
set pid_iterm_limit 30
set pid_iterm_zero 1
set pid_iterm_relax RP
set pid_iterm_relax_cutoff 15
set pid_tpa_scale 10
set pid_tpa_breakpoint 1650
set mixer_sync 1
set mixer_type QUADX
set mixer_yaw_reverse 1
set mixer_throttle_limit_type NONE
set mixer_throttle_limit_percent 100
set mixer_output_limit 100
set output_motor_protocol DISABLED
set output_motor_async 0
set output_motor_rate 480
set output_motor_poles 14
set output_servo_rate 0
set output_min_command 0
set output_min_throttle 1070
set output_max_throttle 2000
set output_dshot_idle 550
set output_dshot_telemetry 0
set output_0 M N 1000 1500 2000
set output_1 M N 1000 1500 2000
set output_2 M N 1000 1500 2000
set output_3 M N 1000 1500 2000
set output_4 M N 1000 1500 2000
set output_5 M N 1000 1500 2000
set output_6 M N 1000 1500 2000
set output_7 M N 1000 1500 2000
set pin_input_rx 35
set pin_output_0 27
set pin_output_1 25
set pin_output_2 4
set pin_output_3 26
set pin_output_4 -1
set pin_output_5 -1
set pin_output_6 -1
set pin_output_7 -1
set pin_buzzer 0
set pin_serial_0_tx 1
set pin_serial_0_rx 3
set pin_serial_1_tx 33
set pin_serial_1_rx 32
set pin_serial_2_tx 17
set pin_serial_2_rx 16
set pin_i2c_scl 22
set pin_i2c_sda 21
set pin_input_adc_0 36
set pin_input_adc_1 39
set pin_spi_0_sck 18
set pin_spi_0_mosi 23
set pin_spi_0_miso 19
set pin_spi_cs_0 5
set pin_spi_cs_1 13
set pin_spi_cs_2 -1
set pin_buzzer_invert 1
set i2c_speed 800
set rescue_config_delay 30
set telemetry_interval 1000
set blackbox_dev 0
set blackbox_mode NORMAL
set blackbox_rate 32
set blackbox_mask 0
set model_name
set wifi_ssid
set wifi_pass
set wifi_tcp_port 1111
set mix_outputs -1
set mix_0 0 0 0
set mix_1 0 0 0
set mix_2 0 0 0
set mix_3 0 0 0
set mix_4 0 0 0
set mix_5 0 0 0
set mix_6 0 0 0
set mix_7 0 0 0
set mix_8 0 0 0
set mix_9 0 0 0
set mix_10 0 0 0
set mix_11 0 0 0
set mix_12 0 0 0
set mix_13 0 0 0
set mix_14 0 0 0
set mix_15 0 0 0
set mix_16 0 0 0
set mix_17 0 0 0
set mix_18 0 0 0
set mix_19 0 0 0
set mix_20 0 0 0
set mix_21 0 0 0
set mix_22 0 0 0
set mix_23 0 0 0
set mix_24 0 0 0
set mix_25 0 0 0
set mix_26 0 0 0
set mix_27 0 0 0
set mix_28 0 0 0
set mix_29 0 0 0
set mix_30 0 0 0
set mix_31 0 0 0
set mix_32 0 0 0
set mix_33 0 0 0
set mix_34 0 0 0
set mix_35 0 0 0
set mix_36 0 0 0
set mix_37 0 0 0
set mix_38 0 0 0
set mix_39 0 0 0
set mix_40 0 0 0
set mix_41 0 0 0
set mix_42 0 0 0
set mix_43 0 0 0
set mix_44 0 0 0
set mix_45 0 0 0
set mix_46 0 0 0
set mix_47 0 0 0
set mix_48 0 0 0
set mix_49 0 0 0
set mix_50 0 0 0
set mix_51 0 0 0
set mix_52 0 0 0
set mix_53 0 0 0
set mix_54 0 0 0
set mix_55 0 0 0
set mix_56 0 0 0
set mix_57 0 0 0
set mix_58 0 0 0
set mix_59 0 0 0
set mix_60 0 0 0
set mix_61 0 0 0
set mix_62 0 0 0
set mix_63 0 0 0
save

rtlopez, 2025-02-15:
PWM is for legacy ESC's, that don't support neither OneShot nor Dshot. Fo coreless motor driven by FETs, you probably want BRUSHED protocol.

copilador, 2025-02-15:
Thanks, I have switched to the BRUSHED protocol, but I get a message that I think means the outputs need to be assigned. I have this configuration for the 4 outputs:
set pin_output_0 27
set pin_output_1 25
set pin_output_2 4
set pin_output_3 26
set pin_output_4 -1
set pin_output_5 -1
set pin_output_6 -1
set pin_output_7 -1

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

copilador, 2025-02-15:
Hi, -in case it's useful- after doing some more testing, it works sometimes??, but most times it doesn't ??

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

rtlopez, 2025-02-15:
If you power from usb, test only one motor at a time. Usb do not have enough power, and board might reset.

copilador, 2025-02-15:
For the power supply, an adjustable laboratory power supply is being used, limiting the current to 2A and the voltage to 3.7V. The 3.7V is for the motors, and 3.3V (XC6220B331MR-G regulator) is for the GY-91 module and the ESP32. I am monitoring if there is a voltage drop, and it remains at 3.3V. The total current consumption with the motors at 100% is around 900mA. What I don’t quite understand is why I get the message:
 Mixer mode problem detected

The Quad X 1234 model needs 4 motor resources and the current configuration of the firmware provides 0 usable output(s) for the selected mode.

If using a custom mixer mode you need to define a custom mmix before changing mixer mode.

Please check your configuration and add the required motor resources.

And why is it sometimes solved just by changing an option in the Motors tab, without having to click Save and Restart? The most curious thing is that in the latest tests, it seems to work correctly.

If you think it's a hardware issue on my end, I will close the topic. Thanks again.

rtlopez, 2025-02-15:
`Quad X 1234` is quite unusual and probably not tested. I suppose this is the reason. use `Quad X` mixer.

copilador, 2025-02-15:
OK, I made the PCB with the Quad X 1234 layout, without thinking it could be an issue

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

Closed 2025-02-15.

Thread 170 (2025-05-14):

No gyro on esp32se

anas-alali-24, 2025-05-14:
Hello

I have uploaded espfc_v0.2.1_esp32s3_0x00.bin  to my drone but i always get no gyro
I tested the gyro with arduino ide  and I am geting the readings there
I used the cli to set the pins for i2c but nothing helps
any Ideas?

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

Thanks

rtlopez, 2025-05-14:
1. what gyro module are you using?
2. describe wiring?
3. go to the cli and type commands: `logs`, `status`, `dump` and attach result here

anas-alali-24, 2025-05-14:
1- mpu6050
2- My own wiring ,but i tested the gyro and it is working
logs

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

status
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

dump
# dump
defaults
set features 536870920
set debug_mode NONE
set debug_axis 1
set gyro_bus AUTO
set gyro_dev AUTO
set gyro_dlpf 256Hz
set gyro_align DEFAULT
set gyro_lpf_type PT1
set gyro_lpf_freq 100
set gyro_lpf2_type PT1
set gyro_lpf2_freq 213
set gyro_lpf3_type FO
set gyro_lpf3_freq 150
set gyro_notch1_freq 0
set gyro_notch1_cutoff 0
set gyro_notch2_freq 0
set gyro_notch2_cutoff 0
set gyro_dyn_lpf_min 170
set gyro_dyn_lpf_max 425
set gyro_dyn_notch_q 300
set gyro_dyn_notch_count 4
set gyro_dyn_notch_min 80
set gyro_dyn_notch_max 400
set gyro_rpm_harmonics 3
set gyro_rpm_q 500
set gyro_rpm_min_freq 100
set gyro_rpm_fade 30
set gyro_rpm_weight_1 100
set gyro_rpm_weight_2 100
set gyro_rpm_weight_3 100
set gyro_rpm_tlm_lpf_freq 150
set gyro_offset_x 0
set gyro_offset_y 0
set gyro_offset_z 0
set accel_bus AUTO
set accel_dev AUTO
set accel_lpf_type BIQUAD
set accel_lpf_freq 15
set accel_offset_x 0
set accel_offset_y 0
set accel_offset_z 0
set mag_bus AUTO
set mag_dev NONE
set mag_align DEFAULT
set mag_filter_type BIQUAD
set mag_filter_lpf 10
set mag_offset_x 0
set mag_offset_y 0
set mag_offset_z 0
set mag_scale_x 1000
set mag_scale_y 1000
set mag_scale_z 1000
set baro_bus AUTO
set baro_dev NONE
set baro_lpf_type BIQUAD
set baro_lpf_freq 10
set board_align_roll 0
set board_align_pitch 0
set board_align_yaw 0
set vbat_source NONE
set vbat_scale 100
set vbat_mul 1
set vbat_div 10
set vbat_cell_warn 350
set ibat_source NONE
set ibat_scale 100
set ibat_offset 0
set fusion_mode MAHONY
set fusion_gain_p 50
set fusion_gain_i 5
set input_rate_type ACTUAL
set input_roll_rate 20
set input_roll_srate 40
set input_roll_expo 0
set input_roll_limit 1998
set input_pitch_rate 20
set input_pitch_srate 40
set input_pitch_expo 0
set input_pitch_limit 1998
set input_yaw_rate 30
set input_yaw_srate 36
set input_yaw_expo 0
set input_yaw_limit 1998
set input_deadband 3
set input_min 885
set input_mid 1500
set input_max 2115
set input_interpolation AUTO
set input_interpolation_interval 26
set input_filter_type FILTER
set input_lpf_type PT3
set input_lpf_freq 0
set input_lpf_factor 50
set input_ff_lpf_type PT3
set input_ff_lpf_freq 0
set input_rssi_channel 0
set input_0 0 1000 1500 2000 A 1500
set input_1 1 1000 1500 2000 A 1500
set input_2 3 1000 1500 2000 A 1500
set input_3 2 1000 1500 2000 A 1000
set input_4 4 1000 1500 2000 H 1500
set input_5 5 1000 1500 2000 H 1500
set input_6 6 1000 1500 2000 H 1500
set input_7 7 1000 1500 2000 H 1500
set input_8 8 1000 1500 2000 H 1500
set input_9 9 1000 1500 2000 H 1500
set input_10 10 1000 1500 2000 H 1500
set input_11 11 1000 1500 2000 H 1500
set input_12 12 1000 1500 2000 H 1500
set input_13 13 1000 1500 2000 H 1500
set input_14 14 1000 1500 2000 H 1500
set input_15 15 1000 1500 2000 H 1500
set failsafe_delay 4
set failsafe_kill_switch 0
set serial_0 1 115200 0
set serial_1 1 115200 0
set serial_2 64 115200 0
set serial_soft_0 1 115200 0
set scaler_0 0 0 20 400
set scaler_1 0 0 20 400
set scaler_2 0 0 20 200
set mode_0 0 4 900 900 0 0
set mode_1 0 4 900 900 0 0
set mode_2 0 4 900 900 0 0
set mode_3 0 4 900 900 0 0
set mode_4 0 4 900 900 0 0
set mode_5 0 4 900 900 0 0
set mode_6 0 4 900 900 0 0
set mode_7 0 4 900 900 0 0
set pid_sync 1
set pid_roll_p 42
set pid_roll_i 85
set pid_roll_d 24
set pid_roll_f 72
set pid_pitch_p 46
set pid_pitch_i 90
set pid_pitch_d 26
set pid_pitch_f 76
set pid_yaw_p 45
set pid_yaw_i 90
set pid_yaw_d 0
set pid_yaw_f 72
set pid_level_p 45
set pid_level_i 0
set pid_level_d 0
set pid_level_angle_limit 55
set pid_level_rate_limit 300
set pid_level_lpf_type PT1
set pid_level_lpf_freq 90
set pid_yaw_lpf_type PT1
set pid_yaw_lpf_freq 90
set pid_dterm_lpf_type PT1
set pid_dterm_lpf_freq 128
set pid_dterm_lpf2_type PT1
set pid_dterm_lpf2_freq 128
set pid_dterm_notch_freq 0
set pid_dterm_notch_cutoff 0
set pid_dterm_dyn_lpf_min 60
set pid_dterm_dyn_lpf_max 145
set pid_dterm_weight 30
set pid_iterm_limit 30
set pid_iterm_zero 1
set pid_iterm_relax RP
set pid_iterm_relax_cutoff 15
set pid_tpa_scale 10
set pid_tpa_breakpoint 1650
set mixer_sync 1
set mixer_type QUADX
set mixer_yaw_reverse 0
set mixer_throttle_limit_type NONE
set mixer_throttle_limit_percent 100
set mixer_output_limit 100
set output_motor_protocol DISABLED
set output_motor_async 0
set output_motor_rate 480
set output_motor_poles 14
set output_servo_rate 0
set output_min_command 1000
set output_min_throttle 1070
set output_max_throttle 2000
set output_dshot_idle 550
set output_dshot_telemetry 0
set output_0 M N 1000 1500 2000
set output_1 M N 1000 1500 2000
set output_2 M N 1000 1500 2000
set output_3 M N 1000 1500 2000
set pin_input_rx 6
set pin_output_0 39
set pin_output_1 40
set pin_output_2 41
set pin_output_3 42
set pin_buzzer 5
set pin_serial_0_tx 43
set pin_serial_0_rx 44
set pin_serial_1_tx 16
set pin_serial_1_rx 15
set pin_serial_2_tx 18
set pin_serial_2_rx 17
set pin_i2c_scl 47
set pin_i2c_sda 21
set pin_input_adc_0 1
set pin_input_adc_1 4
set pin_spi_0_sck 12
set pin_spi_0_mosi 11
set pin_spi_0_miso 13
set pin_spi_cs_0 8
set pin_spi_cs_1 7
set pin_spi_cs_2 -1
set pin_buzzer_invert 1
set i2c_speed 800
set rescue_config_delay 30
set telemetry_interval 1000
set blackbox_dev 0
set blackbox_mode NORMAL
set blackbox_rate 32
set blackbox_mask 0
set model_name
set wifi_ssid
set wifi_pass
set wifi_tcp_port 1111
set mix_outputs -1
set mix_0 0 0 0
set mix_1 0 0 0
set mix_2 0 0 0
set mix_3 0 0 0
set mix_4 0 0 0
set mix_5 0 0 0
set mix_6 0 0 0
set mix_7 0 0 0
set mix_8 0 0 0
set mix_9 0 0 0
set mix_10 0 0 0
set mix_11 0 0 0
set mix_12 0 0 0
set mix_13 0 0 0
set mix_14 0 0 0
set mix_15 0 0 0
set mix_16 0 0 0
set mix_17 0 0 0
set mix_18 0 0 0
set mix_19 0 0 0
set mix_20 0 0 0
set mix_21 0 0 0
set mix_22 0 0 0
set mix_23 0 0 0
set mix_24 0 0 0
set mix_25 0 0 0
set mix_26 0 0 0
set mix_27 0 0 0
set mix_28 0 0 0
set mix_29 0 0 0
set mix_30 0 0 0
set mix_31 0 0 0
set mix_32 0 0 0
set mix_33 0 0 0
set mix_34 0 0 0
set mix_35 0 0 0
set mix_36 0 0 0
set mix_37 0 0 0
set mix_38 0 0 0
set mix_39 0 0 0
set mix_40 0 0 0
set mix_41 0 0 0
set mix_42 0 0 0
set mix_43 0 0 0
set mix_44 0 0 0
set mix_45 0 0 0
set mix_46 0 0 0
set mix_47 0 0 0
set mix_48 0 0 0
set mix_49 0 0 0
set mix_50 0 0 0
set mix_51 0 0 0
set mix_52 0 0 0
set mix_53 0 0 0
set mix_54 0 0 0
set mix_55 0 0 0
set mix_56 0 0 0
set mix_57 0 0 0
set mix_58 0 0 0
set mix_59 0 0 0
set mix_60 0 0 0
set mix_61 0 0 0
set mix_62 0 0 0
set mix_63 0 0 0
save

rtlopez, 2025-05-14:
problem is here `set pin_i2c_scl 47`, I2C gpio number must be lower than 32.

anas-alali-24, 2025-05-14:
Thanks a lot for your response,  I will change it and try it
May I ask is there any reason to be less than 32? It worked with a custom fFC code
Thanks again

rtlopez, 2025-05-14:
there is custom I2C driver, bit limitted but optimized.

anas-alali-24, 2025-05-15:
great working perfectly
but I can't get the receiver to work with elrs
I tested with ppm with flysky and I can see everything is fine , but I tried with Elrs (Radiomaster boxer) no luck, any ideas?

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

Thanks in advance

rtlopez, 2025-05-15:
show ports tab

rtlopez, 2025-05-15:
settings looks good, check your wiring, remember to cross rx-tx between FC and Receiver, keep in mind that uart3 in configurator is pin_serial_2 in cli.

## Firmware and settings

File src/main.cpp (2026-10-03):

#include <Espfc.h>
#include <Hal/FastCode.hpp>
#include <Hal/Platform.hpp>
#include <Hal/Task.hpp>

#ifdef ESP32
void IRAM_ATTR serialEventRun(void) {}
#endif

#if defined(ESP8266) || defined(ARCH_RP2040)
// esp8266 and pico expect C-style linkage
extern "C" void setup();
extern "C" void loop();
extern "C" void setup1();
extern "C" void loop1();
#endif

Espfc::Espfc espfc;

#if ESPFC_HAL_CORE_COUNT > 1
#if defined(ESPFC_HAL_FREE_RTOS)

// RTOS multicore, gyro loop is triggered by the hardware timer interrupt
using Espfc::Hal::Task;

Task::Handle gyroTaskHandle = nullptr;

bool ISR_CODE_ATTR gyroTimerIsr(void* args)
{
  return Task::notifyFromIsr(gyroTaskHandle);
}

void gyroTask(void* pvParameters)
{
  gyroTaskHandle = Task::currentHandle();
  espfc.begin();
  espfc.beginGyroTimer(gyroTimerIsr);
  while (true)
  {
    Task::waitNotify(); // wait for timer isr notification
    espfc.update(true);
  }
}

void pidTask(void* pvParameters)
{
  while (true)
  {
    espfc.updateOther();
  }
}

void setup()
{
  Task::disableIdleWatchdog();
  espfc.load();
  Task::create(gyroTask, "gyroTask", 8192, nullptr, Task::Priority::High, 1);
  Task::create(pidTask, "pidTask", 8192, nullptr, Task::Priority::Low, 0);
  Task::exitCurrent(); // delete arduino loop task
}

void loop() {}

#elif defined(ESPFC_HAL_MULTI_CORE_RP2040)

bool core1_separate_stack = true;
volatile bool setup_done = false;

// RP2040 multicore
// TODO: https://emalliab.wordpress.com/2021/04/18/raspberry-pi-pico-arduino-core-and-timers/
void setup()
{
  espfc.load();
  espfc.begin();
  setup_done = true;
}

void loop()
{
  espfc.update();
}

void setup1()
{
  while (!setup_done)
    ;
}

void loop1()
{
  espfc.updateOther();
}

#else
#error "No RTOS defined for multicore board"
#endif

#else

// single core
void setup()
{
  espfc.load();
  espfc.begin();
}

void loop()
{
  espfc.update();
  espfc.updateOther();
}

#endif

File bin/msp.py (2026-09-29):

#!/usr/bin/env python3
# Requires pyserial: install with `python3 -m pip install pyserial`
# On Ubuntu you can also install it with `sudo apt install python3-serial`
import argparse
import sys
import time
from dataclasses import dataclass

import serial

"""
MSP debug script
"""

TIMEOUT_SECONDS = 3.0
DATAFLASH_TIMEOUT_SECONDS = 0.5
DATAFLASH_RETRIES = 0
MSP_DATAFLASH_SUMMARY = 70
MSP_DATAFLASH_READ = 71
DATAFLASH_READ_SIZE = 256

MSP_STATE_IDLE = 0
MSP_STATE_HEADER_START = 1
MSP_STATE_HEADER_M = 2
MSP_STATE_HEADER_V1 = 3
MSP_STATE_PAYLOAD_V1 = 4
MSP_STATE_CHECKSUM_V1 = 5
MSP_STATE_HEADER_X = 6
MSP_STATE_HEADER_V2 = 7
MSP_STATE_PAYLOAD_V2 = 8
MSP_STATE_CHECKSUM_V2 = 9
MSP_STATE_RECEIVED = 10

MSP_TYPE_CMD = 0
MSP_TYPE_REPLY = 1

MSP_V1 = 0
MSP_V2 = 1


@dataclass
class ParsedFrame:
    version: int
    direction: int
    frame_type: int
    flags: int
    cmd: int
    payload: bytes
    checksum: int
    raw: bytes

    @property
    def header_length(self) -> int:
        return 5 if self.version == MSP_V1 else 8

    @property
    def header(self) -> bytes:
        return self.raw[: self.header_length]


class MspParser:
    def __init__(self) -> None:
        self.reset(full=True)

    def reset(self, full: bool = False) -> None:
        self.state = MSP_STATE_IDLE
        self.version = MSP_V1
        self.direction = MSP_TYPE_CMD
        self.frame_type = 0
        self.flags = 0
        self.cmd = 0
        self.expected = 0
        self.received = 0
        self.checksum = 0
        self.checksum2 = 0
        self.buffer = bytearray()
        self.raw = bytearray() if full else self.raw[:0]

    def feed(self, byte: int):
        c = byte & 0xFF

        if self.state == MSP_STATE_IDLE:
            if c == ord("$"):
                self.raw = bytearray((c,))
                self.state = MSP_STATE_HEADER_START
            return None

        if self.state == MSP_STATE_HEADER_START:
            self.received = 0
            self.checksum = 0
            self.checksum2 = 0
            self.buffer = bytearray()
            self.raw.append(c)
            if c == ord("M"):
                self.version = MSP_V1
                self.state = MSP_STATE_HEADER_M
            elif c == ord("X"):
                self.version = MSP_V2
                self.state = MSP_STATE_HEADER_X
            else:
                self.reset()
            return None

        if self.state == MSP_STATE_HEADER_M:
            self.raw.append(c)
            if c == ord(">"):
                self.direction = MSP_TYPE_REPLY
                self.frame_type = c
                self.state = MSP_STATE_HEADER_V1
            elif c == ord("<"):
                self.direction = MSP_TYPE_CMD
                self.frame_type = c
                self.state = MSP_STATE_HEADER_V1
            elif c == ord("!"):
                self.direction = MSP_TYPE_REPLY
                self.frame_type = c
                self.state = MSP_STATE_HEADER_V1
            else:
                self.reset()
            return None

        if self.state == MSP_STATE_HEADER_X:
            self.raw.append(c)
            if c == ord(">"):
                self.direction = MSP_TYPE_REPLY
                self.frame_type = c
                self.state = MSP_STATE_HEADER_V2
            elif c == ord("<"):
                self.direction = MSP_TYPE_CMD
                self.frame_type = c
                self.state = MSP_STATE_HEADER_V2
            elif c == ord("!"):
                self.direction = MSP_TYPE_REPLY
                self.frame_type = c
                self.state = MSP_STATE_HEADER_V2
            else:
                self.reset()
            return None

        if self.state == MSP_STATE_HEADER_V1:
            self.buffer.append(c)
            self.raw.append(c)
            self.received += 1
            self.checksum ^= c
            if self.received == 2:
                self.expected = self.buffer[0]
                self.cmd = self.buffer[1]
                self.received = 0
                self.buffer = bytearray()
                self.state = (
                    MSP_STATE_PAYLOAD_V1
                    if self.expected > 0
                    else MSP_STATE_CHECKSUM_V1
                )
            return None

        if self.state == MSP_STATE_PAYLOAD_V1:
            self.buffer.append(c)
            self.raw.append(c)
            self.received += 1
            self.checksum ^= c
            if self.received == self.expected:
                self.state = MSP_STATE_CHECKSUM_V1
            return None

        if self.state == MSP_STATE_CHECKSUM_V1:
            self.raw.append(c)
            if self.checksum != c:
                self.reset()
                return None
            frame = ParsedFrame(
                version=self.version,
                direction=self.direction,
                frame_type=self.frame_type,
                flags=0,
                cmd=self.cmd,
                payload=bytes(self.buffer),
                checksum=c,
                raw=bytes(self.raw),
            )
            self.state = MSP_STATE_RECEIVED
            self.reset()
            return frame

        if self.state == MSP_STATE_HEADER_V2:
            self.buffer.append(c)
            self.raw.append(c)
            self.received += 1
            self.checksum2 = crc8_dvb_s2(self.checksum2, c)
            if self.received == 5:
                self.flags = self.buffer[0]
                self.cmd = self.buffer[1] | (self.buffer[2] << 8)
                self.expected = self.buffer[3] | (self.buffer[4] << 8)
                self.received = 0
                self.buffer = bytearray()
                self.state = (
                    MSP_STATE_PAYLOAD_V2
                    if self.expected > 0
                    else MSP_STATE_CHECKSUM_V2
                )
            return None

        if self.state == MSP_STATE_PAYLOAD_V2:
            self.buffer.append(c)
            self.raw.append(c)
            self.received += 1
            self.checksum2 = crc8_dvb_s2(self.checksum2, c)
            if self.received == self.expected:
                self.state = MSP_STATE_CHECKSUM_V2
            return None

        if self.state == MSP_STATE_CHECKSUM_V2:
            self.raw.append(c)
            if self.checksum2 != c:
                self.reset()
                return None
            frame = ParsedFrame(
                version=self.version,
                direction=self.direction,
                frame_type=self.frame_type,
                flags=self.flags,
                cmd=self.cmd,
                payload=bytes(self.buffer),
                checksum=c,
                raw=bytes(self.raw),
            )
            self.state = MSP_STATE_RECEIVED
            self.reset()
            return frame

        self.reset()
        return None
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

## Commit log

2016-12-19 reading sensors + basic pid
2016-12-20 gyro raw and scaled readings
    [gyro_calc.ods]
2016-12-20 3D math refactor + 500Hz gyro rate achived
    [gyro_calc.ods]
2016-12-21 refactor + docs
    [gyro_calc.ods]
2016-12-21 gyro 256hz internal filter
2016-12-23 slerp and kalman sensor fusion
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2017-02-05 ppm input verified, balancing robot frame, 1000hz gyro, input-output passthrough
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2017-02-08 cleaning + complementary filter + outer loop pid
2017-02-18 compass calibration + eeprom
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2017-02-28 gyro and input deadband
2017-03-07 balancing robot control loop rewrite + using complementary filter
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2017-09-03 mixer fir + reset iterm + motor stop
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2017-09-03 avg and pt1 filters are equal
2017-09-03 filter fix + blackbox update
2017-09-04 rates + expo + angle
    [gyro_calc.ods]
2017-09-04 angle mode + flow refactor
2017-09-05 flow refactor + input interpolation + blackbox arming mark + mixer yaw fix
2017-09-12 loop timing + input interpolation + output pwm
2017-09-14 fixes: pwmfast driver + pid + config
2017-09-27 some fixes + tunings
    [gyro_calc.ods]
2017-10-05 1khz + processing flow + oneshot125
    [gyro_calc.ods]
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2017-10-22 next msp commands (pid + filter + rx)
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2017-10-25 no input filter + msp commands + no acc cal on start
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2017-10-27 dterm pid fix + code tidy
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2017-11-01 battery adc
    [gyro_calc.ods]
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2017-11-03 battery monitoring + buzzer
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2017-11-06 pid configuration fix
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2017-11-07 fixes: cpu stats, gyro sync, improves: flight mode switching, disabling accel
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2017-12-01 invert yaw control
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2017-12-06 soft i2c has better performance + uart refactor
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2018-01-23 blackbox rcCommand yaw direction fix
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2018-01-26 split imu fusion into two steps to optimize loop time
2018-02-06 esp8266 esc driver use FRC2 timer for pwm
    [gyro_calc.ods]
2018-02-07 i2c tuning
    [gyro_calc.ods]
2018-02-14 pid rates update + scaler cli status + improve pt1 filter with 2nd order fir
2018-02-15 wiring and schema images
    [espfc_wemos_d1_mini.fzz]
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2018-03-26 i2c error count
2018-03-28 modes fix + pid scale update
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2018-06-09 i2c gyro detect fix
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2018-07-21 esp32 esc driver async attempt
    [gyro_calc.ods]
2018-07-22 esp32 esc driver async fix
    [gyro_calc.ods]
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2018-07-22 esp32 dshot fix
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2018-07-27 acc filter fix + stats mesure refactor
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2018-08-01 esp32 serial communication + better dual core utilization
2018-08-01 sbus test and tidy + 16 channels + throtle interpolate + serial timer
2018-08-02 serial config moved + model storage + pid config + msp
2018-08-02 pitch detection dynamic filter
    [gyro_calc.ods]
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2018-08-16 dynamic filter update + fir2 fix
2018-08-21 deveice detection update
    [gyro_calc.ods]
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2018-09-06 bmp280 baro support
    [calculations.ods, gyro_calc.ods]
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2018-09-17 calibration accel fix + mag update
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2019-04-23 no gyro fix
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2020-06-12 filter tests + ci failure test
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2020-06-22 fix pid settings + more tests
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2020-06-26 fix super rate scaling + fterm filter
    [test_fc.cpp]
2020-06-26 fixes #10 - esp32 disable core0 wdt
    [main.cpp]
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2020-07-16 docs update
    [espfc_wemos_d1_mini.fzz, espfc_wemos_mini32.fzz]
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2020-08-16 diferrent rates support + yaw reverse fix + msp 1.43
    [test_fc.cpp]
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2020-08-20 esp32 fix
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2020-08-26 unattended gyro rate change fix
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2022-09-22 esp32 build fix
2022-09-22 ci test fix + bumb c+14 std
    [test_fc.cpp]
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2022-10-03 working i2c gyro on pico
    [calculations.ods]
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2022-10-07 fixate gyro sample rate + fis tests
    [test_fc.cpp]
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2022-10-22 pico inverted serial + SBUS RX
2022-10-22 esp32/8266 uart build fix
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2022-11-02 serial manager code cleanup
    [calculations.ods]
2022-11-02 pico multi core + enable buzzer + sync tasks
    [main.cpp]
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2022-11-05 spi pins fix on esp targets
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2023-06-18 ICM20602 gyro support + fixes
2023-06-19 imu mahony default and fix
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2023-06-27 esp32 spi fix
2023-07-03 input filtering fix
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2023-07-04 dynamic filter fix
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2023-07-11 track more peaks
    [calculations.ods]
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2023-07-18 buzzer pin fix
2023-07-20 esp32 async esc fix
    [calculations.ods]
2023-07-26 bmp280 spi fix
2023-07-27 I2C fixes
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2023-07-31 revert to soft i2c on esp32
    [calculations.ods]
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2023-08-02 bblog sample rate fix
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2023-08-10 setpoint iterm relax
    [calculations.ods]
2023-08-11 iterm relax in blackbox + filter type cli
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2023-08-16 conf update + dyn notch cli + bat filter
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2023-08-25 optimize pid loop jitter + bblog flushing fix
    [main.cpp]
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2023-08-27 SPI fix
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2023-08-31 gyro align msp fix
2023-09-09 add gyro bmi160 and fix gyro i2c address
2023-09-13 fix bmi160 gyro rate
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2023-11-20 dyn notch activation limit + rp2040 pid loop limit
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2023-12-04 refactor gyro devices + drop gyro/accel fsr + add slave spi bus
2023-12-06 mag on slave i2c bus + better cli stats and logs + i2c speed 800k
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2024-01-30 wiring update
    [esp-fc-esp32-i2c.fzz, esp-fc-esp32-spi.fzz, esp-fc-esp8266-i2c.fzz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]
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2024-02-02 bb buffer + esc off + 4way process command
2024-02-05 fix conflicts + fix tests + 4way motor detection + 4way serial link
    [test_fc.cpp]
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2024-02-14 inverted dshot + rx tx switching
2024-02-15 esc config + msp + cli + rx buffer
2024-02-16 decode gcr + erpm + extended telemetry + esc tests
    [dshot_gcr_dump.txt]
2024-02-21 tune dshot telemetry + more tests
    [dshot_gcr_dump.txt]
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2024-02-25 refactor filters + fix stats
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2024-02-26 optimize rpm filter updates + freq fading + filter weight
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2024-04-08 fix connecting in AP mode + fix async mode in esc driver + docs update
2024-04-18 split pid and filter + rename iram_alt to fast_code
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2024-04-19 sync accel and imu to proceed after pid
2024-04-20 imu sync single core + code tidy + cpu total
    [calculations.ods]
2024-04-23 move fast_code decl to cpp files
    [calculations.ods]
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2024-04-26 reduce max gyro rate to 4k, code tidy
2024-05-07 blackbox mode switch + extend flash size for logs
    [partitions_4M_nota.csv]
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2024-06-21 add pyDrone dump file, pyDrone's PIN definition included
    [pyDrone_dump.txt]
2024-06-25 fix the SPL06's sign bit problem of Pressure Data and Temperature Data.
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2024-10-06 pico multicore fix
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2024-10-27 move rpm and dynamic filter to gyro config
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2025-01-13 move timer to utils, drop timer dependency in escdriver
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2025-01-13 fix esc drivers and pgm imports
2025-02-05 standard c++17
    [partitions_4M_nota.csv]
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2026-05-18 baro device code tidy (#219)
    * cleanup baro device classes, extract .cpp, format code
    * ci actions update
    * ci update upload-artifact action to v7
    * move merge_firmware.py to the /bin dir
2026-05-19 arming angle and acc trim based on PR-198 (#224)
    * Add arming configuration parameters and update processing logic
    * Add trim adjustments for accelerometer calibration
    - Updated ModelState.h to enhance code formatting and organization, including consistent indentation and spacing.
    - Moved enums and structs within the Espfc namespace to improve encapsulation.
    - Refactored AccelSensor class methods for clarity, including the addition of updateTrimRotation method.
    - Improved initialization and calibration logic in AccelSensor to streamline the setup process.
    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
2026-06-22 `ICM42688` IMU support (#227)
    * Add `ICM-42688-P` gyro/accel driver (ICM-42688-P)
    * Register `ICM-42688` driver
    * Test `ICM-42688` driver
    * Return `0` in `begin()` if ICM42688 is sleeping.
    * Fix native test build: add missing include paths for Espfc and EscDriver
    * Add `ICM42688` to supported gyro list in `README`
    * Add include path for `ArduinoFake` in `platformio.ini`
2026-07-10 Alt hold with accel support (#232)
    * calc world acceleration + cleanup sensor fusion
    * altitude vario sensor fusion for alt hold
    * avoid potential data races in accel reading + reduce baro filtering
    * filter delay estimator
    * fix rtqf numerical issues and sanitize fusion mode config
    * optimize and improve rtqf fusion
    * spatial math unit tests
    [bbread.py]
2026-07-27 Code tidy2 (#236)
    * move gyro headers to gyro folder
    * split gyro drivers declarations and definitions
    * tidy gyro delay usage to internal hal
    * tidy i2c/spi bus drivers
    * tidy vtx
    * format sensors
    * rates fix + sensor read sanitization
    * rates unittests fix
    * fft analyzer tidy
    [test_fc.cpp]
2026-08-01 Code tidy3 (#237)
    * connect module tidy
    * Drop PROGMEM usage
    * use std::clamp in place of Utils::clamp
    * fix profiler measurements
    * mixer and msp fixes
    * refomat utils module
2026-08-27 log chip-id while device detection (#241)
    * log chip-id while device detection
    * QMC5883P test connection fix
2026-08-31 Msp v1.48 compatibility (#242)
    * msp_fc_version imitates the BF 2026.6.0
    * msp_mcu_info
    * msp2_sensor_config_active & msp2_gyro_sensor_active
    * msp_attitude_quaternion
    * msp2_get_text & msp2_set_text
    * msp_status & msp_set_rtc & arming_disable_flags
    * simplified tuning init
    * pid_advanced + rc_tuning + compass_config + pid defaults + move tpa
    * msp filter_config
    * msp_rx_config
    * msp_sensor_config
    * sensor_config + sensor_alignment + motor_config
    * drop minthrottle + rename dshot_idle to motor_idle
    * msp_reset_conf + msp_reboot
    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
    [pyDrone_dump.txt]
2026-09-05 Stream api (#243)
    * stream new api
    * migrate logger to new stream api
    * HAL serial + migrate to new stream api
    * migrate to stream api - cleanup
    * isolate gpio hal
    * review fixes + cleanup
    * dyn_notch feature remove + logger buffer with unique_ptr
    * cli - drop dyn_notch feature param
    * blackbox log enum + cli update
    [test_fc.cpp]
2026-09-07 fix: disable f-term in angle mode (#244)
    [test_fc.cpp]
2026-09-11 Move I2C/SPI Bus to Hal (#246)
    * move bus devices (i2c/spi) to Hal
    * isolate hal/bus and arduino
    * handle bus initialization error
2026-09-14 Move board info from target to Hal namespace (#248)
2026-09-17 Move reset reason and usb jtag re-enumeration to Hal (#250)
    * board reset reason
    * usb reenumeration moved to hal
    * target cleanup + serial tx buffer size
    [test_hal.cpp]
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2026-09-20 Hal gpio interrupt and Input RX tidy (#254)
    * Move GPIO interrupts registration to Hal::Gpio
    * Move Input RX to Device::Input namespace
    * InputPPM initialization fix
    [test_hal.cpp]
2026-09-22 Move Adc to Hal (#256)
    [pyDrone_dump.txt]
2026-09-24 Refactor inter-core queue (#257)
    * Refactor inter-core queue
    * multi-core logic fix
    * Move platform specific macros to Hal
    * incorrect Queue type use guard
    [main.cpp, test_hal.cpp]
2026-09-26 Hal timer and pico freertos (#258)
    * HwTimer implementation for various platforms in Hal
    * rpi pico freertos + hot path optimizations
    * pico task affinity
    * unify timer isr handler
2026-09-29 Msp flash read fix (#259)
    * save flash log over jtag usb stall fix
    * dshot bidir flash access in interrupt fix
    * blackbox serial logging fix
    [msp.py]
2026-09-30 Hot path and cli improvements (#261)
    * isr and hot-path optimizations
    * cli more like bf
    * esp32s2 usb build fix
    * cli backspace fix + more cli tests
2026-10-02 Use std::atomic in PPM input (#262)
    * use std::atomic in PPM input
    * thread-safe new data detection
2026-10-03 Dependency cleanup and model initialization (#263)
    * deps cleanup
    * reformat model, refactor initialization
    * compact Model
    * pico hal/task update
    * prevent preserving calibration data when resetting to defaults
    [main.cpp, test_input.cpp]
2026-10-09 Add Arm cmsis-dsp library (#265)
    * better clangd integration
    * Add CmsisDsp library
    * quote include path
2026-10-09 Move FFT to Hal\Dsp and add fft to rp2350 (#266)
    * move fft to hal/dsp
    * rp2350 dsp/fft
    * rp2350 fft fix
    * refactor fft analyzer
    * esp32 fft implementation with radix-2 fallback
    * note about data[1] in the arm CMSIS-DSP backend
    * add CMSIS-DSP complex magnitude implementation
    * Update lib/Espfc/src/Hal/ESP32/Fft.cpp
    ---------
2026-10-20 Use MCPWM Input Capture for PPM Input (#269)
    * ppm update
    * ppm debug off
    * cleanup
    * Keep the timestamp of the last accepted edge when rejecting a short pulse
    * use mcpwm capture for ppm input on esp32 and esp32s3
    * ppm glitch filter
    * ppm attach cleanup + CI build fix
